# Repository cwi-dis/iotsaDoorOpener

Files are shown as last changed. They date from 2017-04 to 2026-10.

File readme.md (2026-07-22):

# iotsaDoorOpener - open a door with RFID or a web browser




Operates a solenoid to open a door. On web access, or when an RFID tag (such as a keychain fob or a mifare contactless transport card) is presented. RFID cards are programmable (over the net, or using a special "learn" card). A web request can be sent to a programmable URL when a card is presented.

The RFID reader functionality and solenoid functionality are contained in individual iotsa extension modules and can be reused, independently of each other.

Home page is <https://github.com/cwi-dis/iotsaDoorOpener>.
This software is licensed under the [MIT license](LICENSE.txt) by the   CWI DIS group, <http://www.dis.cwi.nl>.

## Software requirements

* Arduino IDE, v1.6 or later.
* The iotsa framework, download from <https://github.com/cwi-dis/iotsa>.
* The mfrc522 RFID library, originally by Miguel Balboa, <https://github.com/miguelbalboa/rfid>.

## Hardware requirements

* a iotsa board (or, with some work, another esp8266-based board).
* An MFRC522 RFID reader (search for RC522).
* A electromagnetic door opener, usually a solenoid of some kind.
* A 2N7000 or BS170 MOSFET.
* A NeoPixel, if you want visual feedback.
* Possibly a small relay, like SIP-1A05.

## Hardware construction

The main challenge in construction is catering for the power consumption of the solenoid. The MOSFET is going to be driven with only 3 volt, meaning it will only let about 50-100 mA of current flow (not the 1A max for which the 2N7000 and BS170 are rated). Whether this is enough for your solenoid you have to test, if it is not you need to add a small relay: the MOSFET will trigger the relay easily, and the relay will trigger the solenoid.

Instructions for constructing the hardware are in the _extras_ subfolder:

* [doorOpenerBreadboard.pdf](extras/doorOpenerBreadboard.pdf) is the schematic for use on a breadboard, without a relay. The [Fritzing](http://fritzing.org/home/) project is also available as [doorOpenerBreadboard.fzz](extras/doorOpenerBreadboard.fzz).
* [doorOpenerIotsa.pdf](extras/doorOpenerIotsa.pdf) shows how to put this version together on the iotsa board itself. Fritzing file is there too.
* [doorOpenerIotsaRelay.pdf](extras/DisplayServer-stripboard.pdf) shows how to put the bits together on a stripboard. Again, also available as Fritzing file.

About enclosures: it may be a good idea to mount only the RFID reader on the outside of the door (and the iotsa board and the connection to the solenoid on the inside). If everything is on the inside the RFID reader may not have enough range to get through the door (or frame). If everything is on the outside it is too easy to open the case and operate the solenoid by shorting power to the solenoid.

If you want to mount in two cases: a 3D-printable model for the RFID enclosure can be found at <http://a360.co/2oYSEOF> and an enclosure for the iotsa board can be found in the _extras_ folder of the [Iotsa library](https://github.com/cwi-dis/iotsa).

## Building the software

If you have not changed anything in the design there is nothing to configure. If you have used different GPIO pins look at the _iotsaDoorOpener_ main program and the _iotsaRFID.h_ and _iotsaDoor.h_ include files.

Compile, and flash either using an FTDI or over-the-air.

## Operation

### Initial installation

The first time the board boots it creates a Wifi network with a name similar to _config-iotsa1234_.  Connect a device to that network and visit <http://192.168.4.1>. Configure your device name (we will use _door_ as an example), WiFi name and password, and after reboot the iotsa board should connect to your network and be visible as <http://door.local>.

Visit <http://door.local/door> and use the _Open_ button to operate the solenoid for 2 seconds. If it does not work you may need to add the relay, see _Hardware construction_.

Visit <http://door.local/rfid> to configure RFID cards. The unique ID of the last card presented to the reader is shown here. 

You can add and remove cards that will open the door here too. 

You can also set a "_Master Addition_" and "_Master Removal_" card here. These card will _not_ open the door, but in stead allow you to add other cards (or remove them) without going through the web interface. Present _Master Addition_ and then a new card within a couple of seconds and that new card will be added to the list of known cards.

### Normal operation

The LED will flash white once every 5 seconds or so to show that the door opener is working. 

When you present a known RFID card or tag to the reader the LED will light up green for 2 seconds and the solenoid will operate. 

When you present an unknown card the LED will light up red for two seconds.

When you present the _Master Addition_ card the LED will quickly flash green. You have 2 seconds to present the new card. The LED will go solid green, the door will open, and the new card is now a known card.

When you present the _Master Deletion_ card the LED will quickly flash red. You have 2 seconds to present a known card. The LED will go solid red, and the card is no longer a known card and cannot be used to open the door any more.

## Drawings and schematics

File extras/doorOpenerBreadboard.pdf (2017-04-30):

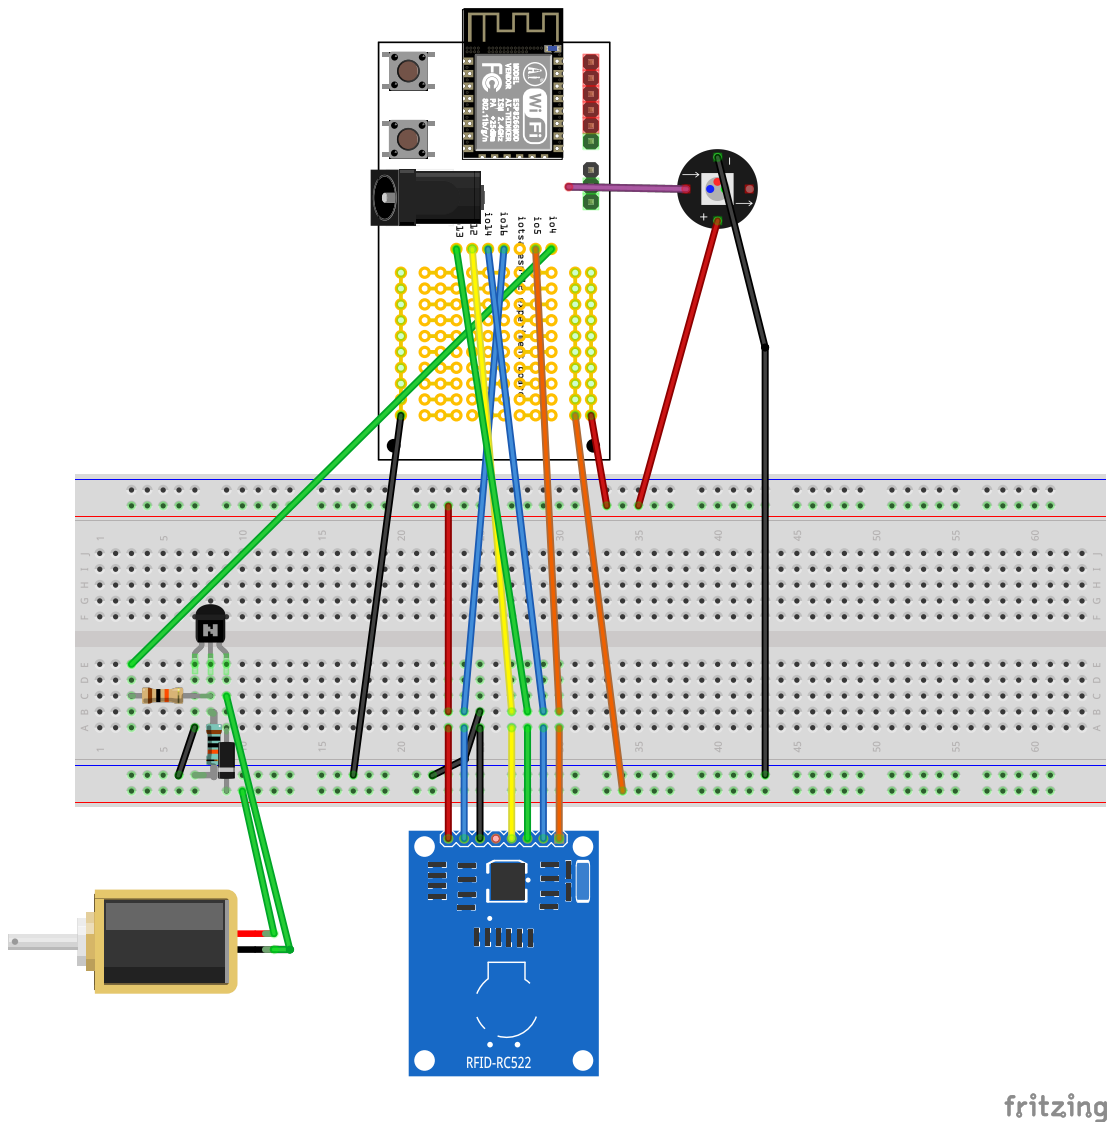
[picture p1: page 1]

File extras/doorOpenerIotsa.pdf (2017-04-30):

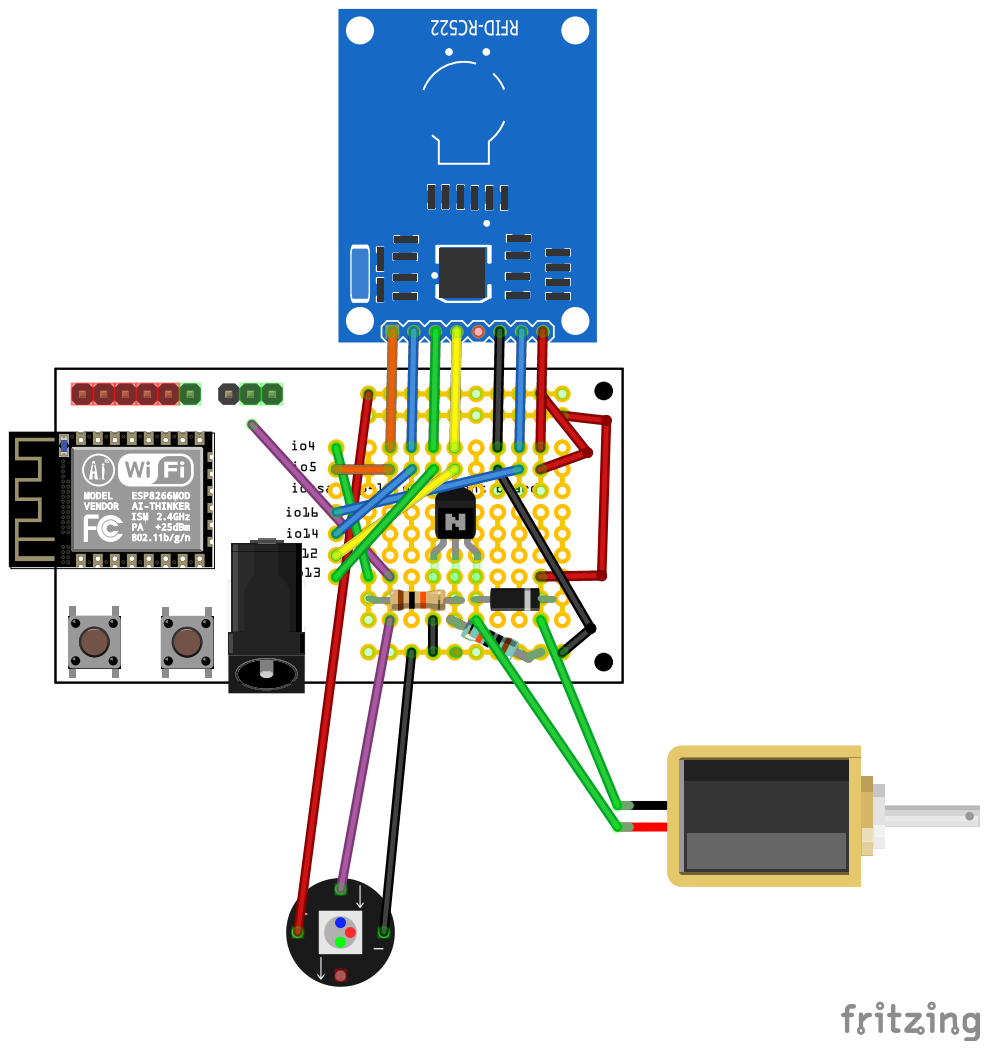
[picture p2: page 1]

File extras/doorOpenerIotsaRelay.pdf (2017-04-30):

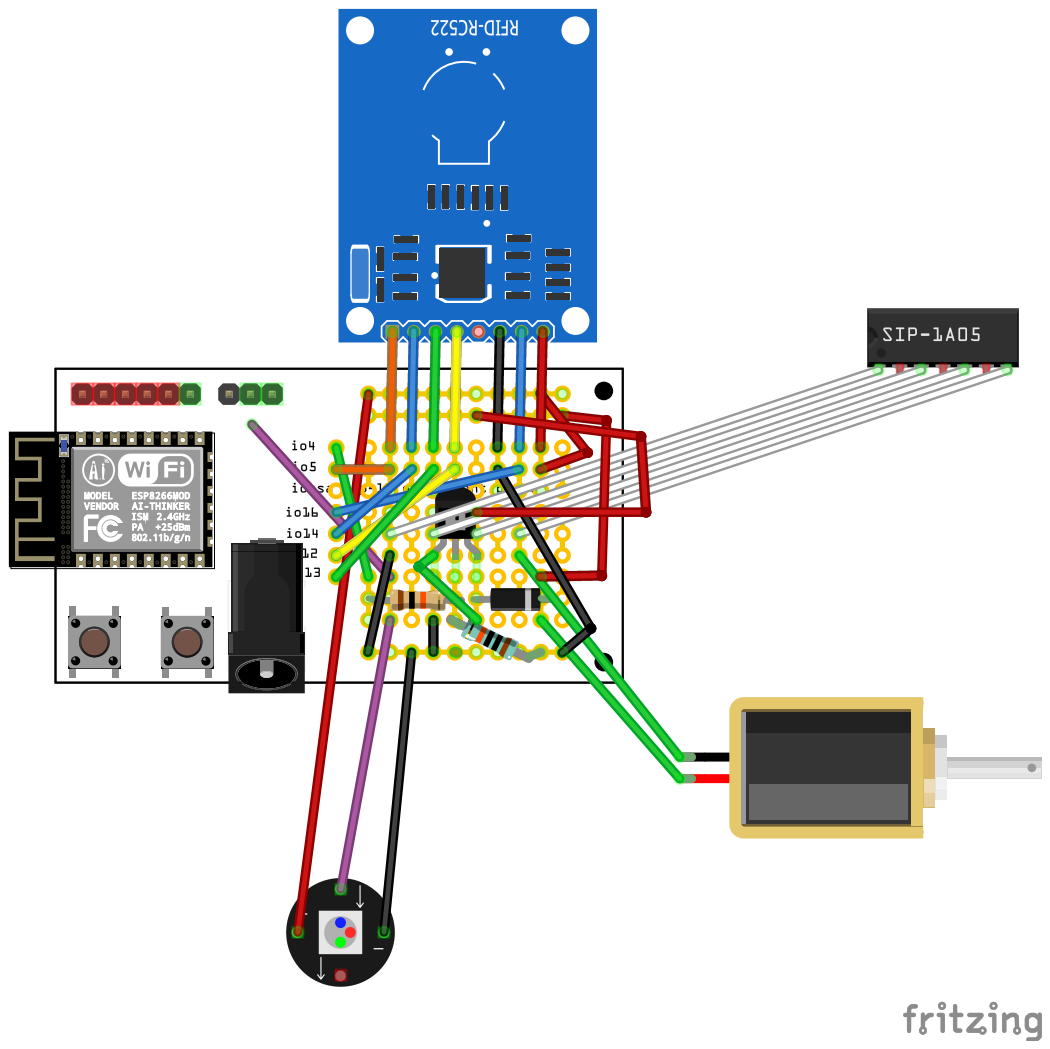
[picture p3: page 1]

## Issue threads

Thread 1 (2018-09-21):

/rfid crashes when there are too many keys

jackjansen, 2018-09-21:
When there are too many keys installed in the device (somewhere between 30 and 40) the device crashes when accessing /rfid. Most likely because the resulting HTML is constructed in an in-core `String` and we overflow either maximum string size or even available RAM.

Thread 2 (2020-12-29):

Needs to be adapted to new ArduinoJson

jackjansen, 2020-12-29:
CI/CD builds are failing. My guess is that this one still uses the old ArduinoJson API.

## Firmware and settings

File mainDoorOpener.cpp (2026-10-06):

//
// Opens a door with a solenoid, triggered by an RFID card/tag or a web/REST request.
// See readme.md for hardware and operation details.
//

#include "iotsa.h"
#include "iotsaRFID.h"
#include "iotsaDoor.h"
#include "iotsaUser.h"

IotsaApplication application("Door Opening Server");
IotsaUserMod myAuthenticator(application, "admin");


// Instantiate the Door module, and install it in the framework
IotsaDoorMod doorMod(application);

// Instantiate the RFID module, and install it in the framework
IotsaRFIDMod rfidMod(application);

void openDoor(String& uid) {
  doorMod.openDoor();
}

void onSolenoidDeactivated() {
  rfidMod.scheduleReset();
}

// LED feedback for RFID mode changes, via iotsaStatus's status-pulse channel
// (cwi-dis/iotsa#176/#256) instead of ledMod.set(). IotsaRFIDMod calls
// modeChanged() -- and so showMode() -- at every real mode transition,
// including the return to card_idle (both the loop() timeout and an
// immediate add/remove success), so card_idle's clearStatusPulse() always
// lands exactly when the RFID module's own window really ends. The
// durations passed for card_add/card_remove below are just a safety cap in
// case that callback is ever skipped -- they don't need to match
// IotsaRFIDMod's real 5-second window exactly.
static const uint32_t kRfidPulseCapMs = 6000;

void showMode(cardMode mode) {
  if (mode == card_ok) {
    iotsaStatus.setStatusPulse(0x00ff00, 0, 0, 2000, "card ok");  // 2 seconds green
    IotsaSerial.println("showMode: card_ok");
  } else if (mode == card_bad) {
    iotsaStatus.setStatusPulse(0xff0000, 0, 0, 2000, "card bad");  // 2 seconds red
    IotsaSerial.println("showMode: card_bad");
  } else if (mode == card_add) {
    iotsaStatus.setStatusPulse(0x00ff00, 250, 250, kRfidPulseCapMs, "present card to add");  // green flashing
    IotsaSerial.println("showMode: card_add");
  } else if (mode == card_remove) {
    iotsaStatus.setStatusPulse(0xff0000, 250, 250, kRfidPulseCapMs, "present card to remove");  // red flashing
    IotsaSerial.println("showMode: card_remove");
  } else {
    iotsaStatus.clearStatusPulse(); // Resume normal iotsa status display
    IotsaSerial.println("showMode: iotsa status");
  }
}

// Standard setup() method, hands off most work to the application framework
void setup(void){
  application.setAuth(&myAuthenticator);  // every module, the standard ones included, uses this
  application.setup();
  application.lateSetup();
  rfidMod.cardPresented = openDoor;
  rfidMod.modeChanged = showMode;
  doorMod.solenoidDeactivated = onSolenoidDeactivated;
  showMode(card_idle);
}

// Standard loop() routine, hands off most work to the application framework
void loop(void){
  application.loop();
}

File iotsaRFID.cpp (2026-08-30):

#include "iotsa.h"
#include "iotsaRFID.h"
#include "iotsaConfigFile.h"

// Helper function: convert RFID UID to string

static String strUid(MFRC522::Uid& uid) {
  String rv;
  for (int i=0; i<uid.size; i++) {
    char c1 = "0123456789ABCDEF"[((uid.uidByte[i] >> 4) & 0xf)];
    char c2 = "0123456789ABCDEF"[(uid.uidByte[i] & 0xf)];
    rv += c1;
    rv += c2;
  }
  return rv;
}

bool IotsaRFIDMod::lookupCard(const String& uid) {
  auto it = normalCards.find(uid);
  bool ok = it != normalCards.end();
  return ok;
}

void IotsaRFIDMod::handleAddCard(const String& uid) {
  auto it = normalCards.find(uid);
  if (it == normalCards.end()) {
    normalCards.insert(uid);
    IotsaSerial.print("rfid: added card: ");
    IotsaSerial.println(uid);
  }
}

void IotsaRFIDMod::handleRemoveCard(const String& uid) {
  auto it = normalCards.find(uid);
  if (it != normalCards.end()) {
    normalCards.erase(it);
    IotsaSerial.print("rfid: Removed card: ");
    IotsaSerial.println(uid);
  }
}

//
// Implementation of the RFID module
//
void IotsaRFIDMod::setup() {
  SPI.begin();
  mfrc522.PCD_Init();
  chipVersion = mfrc522.PCD_ReadRegister(MFRC522::VersionReg);
  // 0x00 and 0xFF are not valid MFRC522 firmware versions - both are what a floating/dead
  // SPI bus reads back, i.e. no chip actually answering (unplugged, unpowered, miswired).
  chipPresent = (chipVersion != 0x00 && chipVersion != 0xFF);
  if (chipPresent) {
    IotsaSerial.print("rfid: MFRC522 VersionReg=0x");
    IotsaSerial.println(chipVersion, HEX);
  } else {
    IotsaSerial.print("rfid: MFRC522 not detected (VersionReg=0x");
    IotsaSerial.print(chipVersion, HEX);
    IotsaSerial.println("), check reader wiring/power");
  }
  configLoad();
}

void IotsaRFIDMod::scheduleReset() {
  if (resetAfterSolenoidMs == 0) return;
  pendingResetAtMillis = millis() + resetAfterSolenoidMs;
}

void IotsaRFIDMod::resetChip() {
  IotsaSerial.println("rfid: resetChip requested");
  mfrc522.PCD_Init();
  resetCount++;
  lastResetTime = millis();
  IotsaSerial.print("rfid: resetChip done, VersionReg=0x");
  IotsaSerial.println(mfrc522.PCD_ReadRegister(MFRC522::VersionReg), HEX);
}

void
IotsaRFIDMod::webHandler() {
  // Handles the page that is specific to the RFID module.
  if (needsAuthentication()) return;
  bool anyChanged = false;
  if (api.webService->server->hasArg("addCard") && api.webService->server->arg("addCard") != addCard) {
    anyChanged = true;
    addCard = api.webService->server->arg("addCard");
    IotsaSerial.print("Set addCard: ");
    IotsaSerial.println(addCard);
  }
  if (api.webService->server->hasArg("removeCard") && api.webService->server->arg("removeCard") != removeCard) {
    anyChanged = true;
    removeCard = api.webService->server->arg("removeCard");
    IotsaSerial.print("Set removeCard: ");
    IotsaSerial.println(removeCard);
  }
  if (api.webService->server->hasArg("normalAdd") && api.webService->server->arg("normalAdd") != "") {
    anyChanged = true;
    handleAddCard(api.webService->server->arg("normalAdd"));
  }
  if (api.webService->server->hasArg("normalRemove") && api.webService->server->arg("normalRemove") != "") {
    anyChanged = true;
    handleRemoveCard(api.webService->server->arg("normalRemove"));
  }
  if (anyChanged) configSave();

  // Stream the response instead of building one big in-core String: with enough
  // known cards (~30-40) that String overflowed available RAM and crashed the
  // device (cwi-dis/iotsaDoorOpener#1). Each sendContent() call only ever holds
  // one card's worth of HTML at a time, so this is bounded regardless of how
  // many cards are known.
#ifdef CONTENT_LENGTH_UNKNOWN
  api.webService->server->setContentLength(CONTENT_LENGTH_UNKNOWN);
#endif
  api.webService->server->send(200, "text/html");
  api.webService->server->sendContent("<html><head><title>RFID Server</title></head><body><h1>RFID Server</h1>");
  if (lastCard != "") {
    String message = "<p>Last card was presented " + String((millis()-lastCardReadTime)/1000) + " seconds ago, Card ID " + lastCard;
    if (!lastCardKnown) message += " (unknown)";
    message += ".</p>";
    api.webService->server->sendContent(message);
  } else {
    api.webService->server->sendContent("<p>No card presented since last power-on.</p>");
  }

  String form = "<h2>Adding Cards</h2><form method='get'>Master addition card ID: <input name='addCard' value='";
  form += addCard;
  form += "'><br>Master removal card ID: <input name='removeCard' value='";
  form += removeCard;
  form += "'><br>Manually add normal card: <input name='normalAdd'><br><input type='submit'></form>";
  api.webService->server->sendContent(form);

  api.webService->server->sendContent("<h2>Known Cards</h2><ul>");
  for (auto it=normalCards.begin(); it != normalCards.end(); it++) {
    api.webService->server->sendContent("<li>" + *it + "(<a href='/rfid?normalRemove=" + *it + "'>remove</a>)</li>");
  }
  api.webService->server->sendContent("</ul></body></html>");
}
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

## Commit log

2017-04-28 Renaming things to prepare for git migration
    [doorOpenerBreadboard.fzz, doorOpenerIotsa.fzz, doorOpenerIotsaRelay.fzz]
2018-03-06 Fixed for iotsa 1.4
    [iotsaRFID.h, iotsaSolenoid.cpp]
2018-03-15 Added ArduinoJWT dependency
2020-12-31 Adapted for new ArduinoJson API (finally)
2021-01-03 Build all iotsa products for at least nodemcuv2 and esp32thing
2021-01-03 Use board_build.ldscript
2021-01-03 Fixed to compile on esp32
2024-12-23 Changed for new version of ArduinoJson.
2025-04-27 Updated arduino build job
2026-07-22 #149 bullet 2: fix code-structure warts in IotsaRFIDMod/IotsaDoorMod
    - Move both modules' actual state (RFID reader + known-card set,
    solenoid timers) from file-scope globals into class members, so each
    module owns its own state per the current convention.
    - Rename iotsaSolenoid.h/.cpp to iotsaDoor.h/.cpp to match the class
    they actually define (IotsaDoorMod), and fix a header-guard typo
    (SOLENIOD -> DOOR).
    - Modernize both handler()s from a server->args()-index scan to
    hasArg(), matching the style already used elsewhere.
    - Replace the unedited Skeleton-template header comment in the .ino
    with an accurate description.
    [iotsaDoor.cpp, iotsaRFID.cpp, iotsaRFID.h]
2026-07-22 #149 bullet 4 + fix /rfid crash with many known cards (#1)
    Bullet 4 (REST/backup-restore conformance): IotsaDoorMod had no real
    persistent config (opening the door is a momentary trigger, not a
    config change) yet still registered a POST-only /api/door and set
    name="door", making it visible to iotsa backup/restore for no reason
    -- iotsa backup would write a door.json containing null. Dropped
    IotsaApiMod/api/name entirely, keeping only the existing plain /door
    web endpoint, matching the same REST-is-config-only principle already
    applied to iotsaSmartMeter's IotsaP1Mod.
    Also fixed cwi-dis/iotsaDoorOpener#1: IotsaRFIDMod::handler() built the
    entire known-cards list into one in-core String, whic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
    [iotsaDoor.cpp, iotsaRFID.cpp]
2026-07-27 Modernize file structure, drop IotsaFilesBackupMod
    Move app glue from iotsaDoorOpener.ino into mainDoorOpener.cpp,
    matching the current iotsa/lissabon file-structure convention while
    keeping Arduino IDE compatibility (bare #include <iotsa.h> .ino).
    Also drop IotsaFilesBackupMod: the new iotsa backup/restore CLI
    commands use the generic per-module /api/* mechanism, not
    /backup.tar, so this module was dead weight (already dropped in
    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
2026-07-27 #4: modernize RFID logging, expose read telemetry over REST
    Log the MFRC522 chip's VersionReg once at setup(). In loop(), call
    PICC_Select() directly instead of the PICC_ReadCardSerial() wrapper
    so the StatusCode is available: a card seen but failing to read
    (previously silent) is now logged with the actual error, plus
    ErrorReg/CollReg snapshotted. Successful reads log UID and PICC type.
    /api/rfid now exposes lastCardType and a telemetry sub-object
    (chipVersion, antennaGain, last read-attempt success/status/error
    registers) for remote debugging of read failures - e.g. the ongoing
    m377door new-keyfob investigation.
    D1 onboard reader LED (also part of #4) is left for a follow-up,
    pending a p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
    [iotsaRFID.cpp, iotsaRFID.h]
2026-07-27 #4: detect and flag a disconnected/dead MFRC522 chip
    VersionReg reads back 0x00 or 0xFF when nothing is answering on the SPI
    bus (unplugged, unpowered, miswired) - a real chip never reports either.
    Detect this explicitly at setup() instead of surfacing it as plausible-
    looking but meaningless numbers downstream (confirmed testing today:
    antennaGain read back as a bogus-but-plausible 0x70, since it's just
    0xFF masked with 0x70).
    - setup() logs a clear "not detected" message instead of a bare hex dump
    - /api/rfid telemetry gains chipPresent, and omits antennaGain entirely
    when no chip was found
    - loop() skips polling altogether when no chip was detected at boot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
    [iotsaRFID.cpp, iotsaRFID.h]
2026-07-28 Disable HTTPS on the esp8266 env - BearSSL too slow/unstable in practice
    Config PUTs over HTTPS took up to a minute and intermittently crashed
    the device inside Espressif's WiFi SDK (SoftAP probe-response
    handling). Same class of resource exhaustion as cwi-dis/iotsa#159.
    esp32thing is unaffected and keeps HTTPS via the common build flags.
2026-07-31 Fix /api/rfid missing 'cards' field, prefix log lines with source
    reply["cards"].as<JsonArray>() is a non-mutating cast in ArduinoJson 7:
    since the variant was null, it never created the array, so rCards.add()
    was a silent no-op and the "cards" key never made it into the response
    (regression from 983312c's ArduinoJson 6->7 port, found while checking
    /api/rfid on m377door for #5). Use .to<JsonArray>(), matching the
    telemetry object a few lines below.
    Also prefix IotsaSerial log lines with their source (rfid:, showMode:)
    for easier reading when interleaved with other modules' output.
    [iotsaRFID.cpp, mainDoorOpener.cpp]
2026-08-07 #7: live RFID telemetry (chipPresent/antennaOn) and manual resetChip() recovery
    /api/rfid previously reported stale setup()-time chipVersion/chipPresent instead
    of live register reads, making it useless for distinguishing a genuinely dead
    chip from one stuck but still answering SPI. Now reads chipVersion/chipPresent
    live on every request (chipPresentAtBoot keeps the old snapshot), and adds
    antennaOn (TxControlReg) alongside the existing antennaGain (RFCfgReg) - a
    different register entirely, and the one that actually confirmed the
    antenna-disabled hypothesis behind the RFID-goes-deaf-after-solenoid bug.
    Also adds resetChip(), exposed as a momentary PUT /api/rfid {"resetChip": true}
    action (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
    [iotsaRFID.cpp, iotsaRFID.h]
2026-08-07 #7: auto-recover RFID reader via decoupled door/RFID callback
    Wires up automatic resetChip() recovery after a solenoid activation, without
    creating a dependency between IotsaDoorMod and IotsaRFIDMod: IotsaDoorMod gains
    a public solenoidDeactivated callback (fired once in loop() right as the
    solenoid switches off, same style as the existing cardPresented/modeChanged
    callbacks), and IotsaRFIDMod gains a non-blocking scheduleReset() driven by a
    new persisted/REST-configurable resetAfterSolenoidMs field (0 = disabled,
    opt-in). mainDoorOpener.cpp is the only place that wires the two together.
    Confirmed end-to-end on pampusdoor with resetAfterSolenoidMs=1000: resetChip()
    fires automatically ~1s a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
    [iotsaDoor.cpp, iotsaRFID.cpp, iotsaRFID.h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]
2026-08-11 Remove redundant ESP.wdtEnable() call in mainDoorOpener setup()
    IotsaApplication::setup() already enables the watchdog for ESP8266 builds;
    the app-level call was a harmless but pointless duplicate. Verified on the
    desk immersiondoor (see #8) that the framework watchdog call alone is
    sufficient and does trigger a reboot on a real hang.
    [mainDoorOpener.cpp]
2026-08-12 Use cmArduinoJWT fork instead of unmaintained ArduinoJWT
    Fixes cwi-dis/iotsa#184
2026-08-13 Replace fork --git-url installs with Library Manager references in Arduino CI
    cmArduinoJWT and esp32_idf5_https_server_compat are now published in the
    Arduino Library Manager, so the arduino-cli workflow no longer needs
    --git-url installs for them (esp32_idf5_https_server resolves
    transitively via esp32_idf5_https_server_compat's own depends=). iotsa
    itself is still installed via --git-url, pinned to the branch/ref under
    test.
    cwi-dis/iotsa#96
2026-08-13 arduino-cli: force a fresh library index before name-based lib installs
    The previous commit switched cmArduinoJWT and esp32_idf5_https_server_compat
    from --git-url installs to name-based Library Manager lookups. That exposed
    a latent bug in the "Cache Arduino CLI" step: its cache key hashes
    *_index.json in the repo working directory, which doesn't exist here, so
    the key is effectively static and a cache-hit silently restores whatever
    library_index.json was saved on the very first run -- forever, since
    arduino-cli only auto-downloads that index when it's completely absent,
    never when it's merely stale.
    Confirmed locally (with arduino-cli installed via brew): installing
    cmArduinoJWT against a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
2026-08-14 ci: bump GitHub Actions to current majors (checkout@v7, setup-python@v7, upload-artifact@v7, cache@v6)
    These were pinned to versions from 2020-2021 (checkout@v2, setup-python@v2 -
    both Node16, upload-artifact@v4, cache@v2), well past their supported
    window. Matches the versions already verified working in iotsa itself.
2026-08-30 Migrate to iotsa v3 API + vendor board definitions
    v3 API (cwi-dis/iotsa#199):
    - IotsaDoorMod: IotsaMod -> IotsaBaseModule; serverSetup() -> lateSetup();
    it has no api of its own, so the /door page stays a hand-registered
    app.server->on() route and the handler body uses app.server->.
    - IotsaRFIDMod: IotsaApiMod -> IotsaModule; serverSetup() -> lateSetup();
    handler() -> webHandler() override; server-> -> api.webService->server->;
    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
2026-08-31 board-defs: re-vendor from iotsa v3.0a2
    Re-vendor iotsa-board-defs.ini verbatim from iotsa v3.0a2: [lolin32]
    now correctly resolves to board = lolin32_lite (cwi-dis/iotsa#228), plus the
    new [lolin32_oled] (cwi-dis/iotsa#229) and completed [crowpanel128] fields
    (cwi-dis/iotsa#226). This repo uses none of those sections; refresh only.
    Claude-Session: https://claude.ai/code/session_01JK4ha63zeEirSaBRkjhC4p
2026-09-20 Migrate showMode() LED feedback to iotsaStatus.setStatusPulse()
    ledMod.set()/showStatus() are gone from iotsa core (cwi-dis/iotsa#256). The
    card_add/card_remove flashing durations are just a safety cap now, not a
    value that has to be hand-tuned to match IotsaRFIDMod's real timeout:
    modeChanged() always fires at the real end of a mode (both the loop()
    timeout and an immediate add/remove success), so card_idle's
    clearStatusPulse() lands exactly when the RFID module's own window closes.
2026-10-05 Re-vendor iotsa board definitions; drop redundant min_spiffs.csv lines
    Refreshes iotsa-board-traits.ini / iotsa-board-defs.ini from iotsa
    develop (last vendored 2026-08-31). Picks up:
    - espressif32 platform pinned to 7.1.3 (cwi-dis/iotsa#269)
    - board_build.filesystem = littlefs, so `pio run -t uploadfs` builds an
    image the firmware can mount (cwi-dis/iotsa#269)
    - min_spiffs.csv as the default partition layout for all 4MB ESP32
    boards (cwi-dis/iotsa#245), making local board_build.partitions =
    min_spiffs.csv lines redundant -- removed where present
    - the NimBLE host-task stack flag for all ESP32 builds (cwi-dis/iotsa#127)
    Resolved config checked before/after with `pio project config`: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
2026-10-06 Adapt to iotsa's standard modules and per-application authenticator
    Re-vendor iotsa-board-traits.ini / iotsa-board-defs.ini from iotsa
    develop (status LED defines: IOTSA_PIN_LED, IOTSA_LED_NEOPIXEL,
    IOTSA_LED_ACTIVE_LOW).
    - Drop the IotsaWifiMod/IotsaOtaMod declarations: iotsa now creates the
    WiFi and OTA modules automatically (cwi-dis/iotsa#85).
    - Drop the status-LED declaration (NeoPixel on GPIO15): iotsa creates it
    from the board definition, iotsa_v4 has it on that pin (cwi-dis/iotsa#272).
    - Module constructors no longer take an authenticator: modules use the
    application's one (cwi-dis/iotsa#284).
    - application.setAuth() sets the authenticator, used by every module, the
    standard o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
    [iotsaRFID.h, mainDoorOpener.cpp]
2026-10-24 iotsa 3.0a15: cards as an IotsaCollection of {"uid": ...}, log macros, board files
    The cards are an IotsaVector keyed by UID (cwi-dis/iotsa#309): "cards":
    [{"uid": ...}, ...] in GET and to replace all, {"cards": {"<uid>": {}}} to
    add one, null to remove. A backup from before 3.0 has strings and must be
    converted first (see the readme). Logging through IOTSA_LOG/IOTSA_LOG_DEBUG
    (cwi-dis/iotsa#182). Board files refreshed (HTTPS_LOGLEVEL=2).
